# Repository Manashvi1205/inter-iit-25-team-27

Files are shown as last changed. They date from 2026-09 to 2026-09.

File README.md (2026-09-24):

# Autonomous Rover for Warehouse Rack Inventory

Warehouse records drift. Items get picked, put back on the wrong shelf, or never scanned, and the database stops matching the rack. This rover closes that gap on the floor. It drives the aisle, stops in front of a bay, runs a camera up the rack face, reads the label at each level, and writes the result to a live inventory view.

The machine is a full mobile robot, not a camera on a stick. A ~25 kg differential-drive base carries compute, LiDAR, batteries, and motor drivers. A belt-driven mast lifts the camera from the floor to about 1.8 m. Three Arduino Megas and an ESP32 handle motors, encoders, the IMU, and the pan-tilt, while a Jetson Orin Nano runs ROS 2 navigation and the scan.

The design targets are concrete: align with a rack to better than ±10 cm horizontally and ±2 cm vertically, scan a 1.8 m rack segment in under 3 minutes at 1920×1080, decode 5 cm labels with better than 90% success, and stop in under 500 ms on an emergency press.

<p align="center">
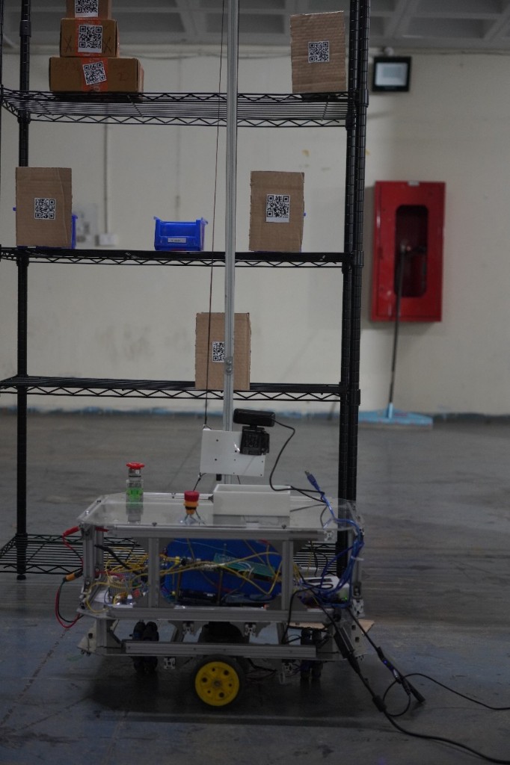
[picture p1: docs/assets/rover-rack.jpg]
Rover stopped at a rack with the camera carriage on the mast
  
</p>

The rover in front of a rack. The camera carriage sits on the mast; the clear deck holds the battery, controllers, and emergency stop.

---

## How a run works

1. The operator gives a goal in the mapped warehouse. Nav2 plans a path on the occupancy grid and the base drives to the bay.
2. The base settles in front of the rack. Wheel encoders, the BNO055, and the RPLiDAR keep the pose stable enough for the camera to face the shelf.
3. The IG45 lift motor runs the timing belt until the carriage is at the next shelf height. Encoder ticks are mapped at 163 ticks per centimetre of travel.
4. If a label sits at the edge of the frame, two SC15 servos pan and tilt the camera. The IMX258 then captures the shelf.
5. The vision node detects the code, projects it onto the rack plane, and logs rack, shelf, item id, and pose. Duplicates from the same stop are dropped.
6. The Flask dashboard reads that table and shows which slots are filled, which are empty, and what the rover just did.

Two streams run at once. Motion data (`/scan`, `/imu`, `/odom`) stays on the Jetson and never waits for the website. Scan results are written beside that pipeline and served to the operator over HTTP, so a slow browser refresh cannot stall navigation.

---

## Base

The footprint stays inside 600 mm × 450 mm so the robot can turn inside an aisle. The centre of rotation sits near the geometric centre: two driven wheels on the sides, one caster at the front and one at the rear. All four share the load, and the corners stay inside the clearance next to the racks.

The load-bearing plate is 3 mm aluminium. The other decks are 3 mm acrylic, held in 2020 aluminium extrusion with M5 fasteners (M4 and M3 on mounts and hubs). Mild-steel shafts carry the rotating parts. Edges are chamfered and covered by the extrusion so there are no sharp corners at shin height.

<p align="center">
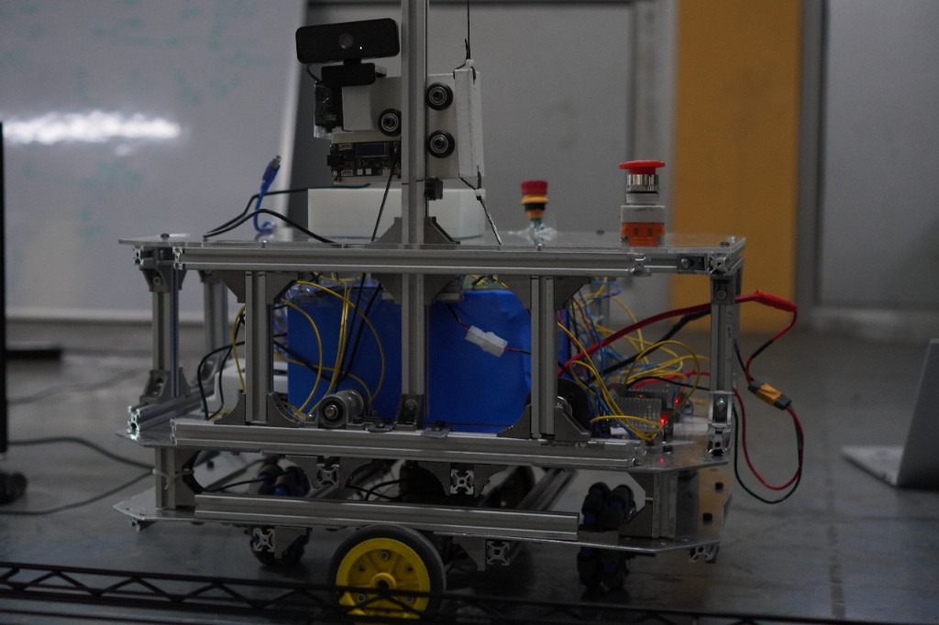
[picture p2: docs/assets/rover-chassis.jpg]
Side view of the aluminium chassis, batteries, wiring, and emergency stop
  
</p>

Drive is two IG42 planetary gearmotors with built-in encoders, through one Cytron MDD10A. The Mega closes the speed loop from the encoder counts and publishes wheel odometry to the Jetson over serial. HD rubber wheels are sized for smooth warehouse floors: enough grip to start and stop a 25 kg robot without the slip that would wreck the odometry.

The second MDD10A drives the mast motor on the same style of PWM and direction interface, so base and lift look the same to the controller. The Jetson sends velocity and a Z target; the Mega turns those into PWM.

---

## Mast

Vertical travel is a continuous timing belt on a rigid extrusion column. The belt stays in one plane over the motor pulley, a top idler, and an in-line idler, so the carriage is pulled both up and down instead of relying on friction. A long bolt acts as a passive tensioner. Guided rollers keep the carriage from twisting when the camera and servo board are on it.

Clockwise rotation of the IG45 lowers the carriage; counter-clockwise raises it. Because the column is stiff, the lift does not run a second position loop on the Jetson. A constant PWM runs until the encoder count matches the shelf height. Limit switches at the top and bottom are wired normally closed and cut the motor if the carriage travels past the stroke.

On the carriage, two SC15 bus servos add pan and tilt. A Waveshare ESP32 board on the carriage drives them and reports angle, so the vision node knows where the camera was pointing when the frame was taken. At the end of a session the camera is sent back to a recorded home pose.

<p align="center">
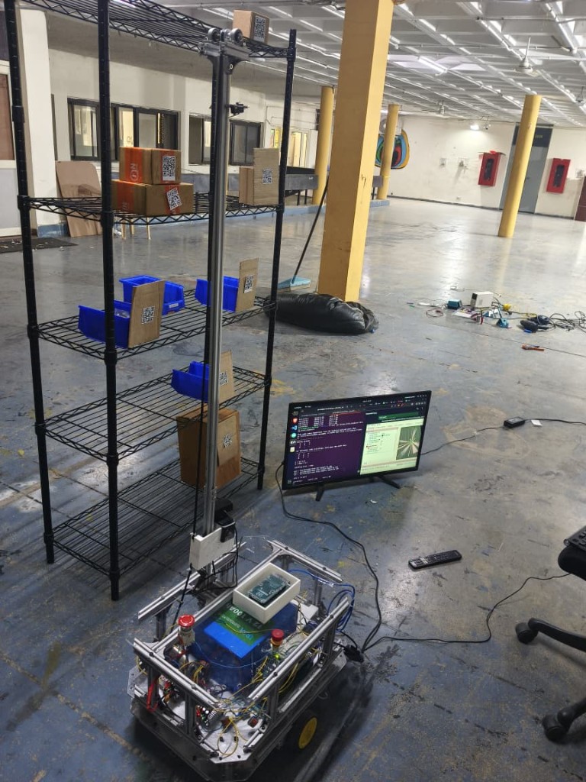
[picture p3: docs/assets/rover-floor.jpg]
Full rover on the warehouse floor, mast raised beside a rack, LiDAR view on a monitor
  
</p>

---

## Navigation

Localisation is three measurements fused on purpose.

- Wheel encoders give short-term motion, including the lift height.
- The BNO055, on its own Mega over I2C, publishes fused orientation. The chip does the sensor fusion onboard and outputs a quaternion, so the robot does not run a separate attitude filter.
- The RPLiDAR S2E sweeps 360° out to 30 m at over 10 kHz. It talks to the Jetson over Ethernet, not USB, for bandwidth and noise. The laser is eye-safe for people working next to the aisle.

An EKF (`robot_localization`) fuses encoders and IMU into `/odom` and the `odom` → `base_link` transform. SLAM Toolbox consumes `/scan` plus that pose, builds a 2D occupancy grid, and publishes `map` → `odom`, which is what removes long-term drift. The static `base_link` → `laser` transform is the LiDAR mount.

Nav2 plans on that map. The global planner is NavFn with A*. The local controller is DWB: it samples twists around the nominal command and scores them against the costmaps, which matters because the two drive motors are not perfectly matched and the base would otherwise walk off the path. Costmaps are layered — static map, live obstacle inserts from the LiDAR, and an inflation layer around the footprint. If the local planner cannot find a safe command, the behaviour tree clears the costmap, spins, or replans.

<p align="center">
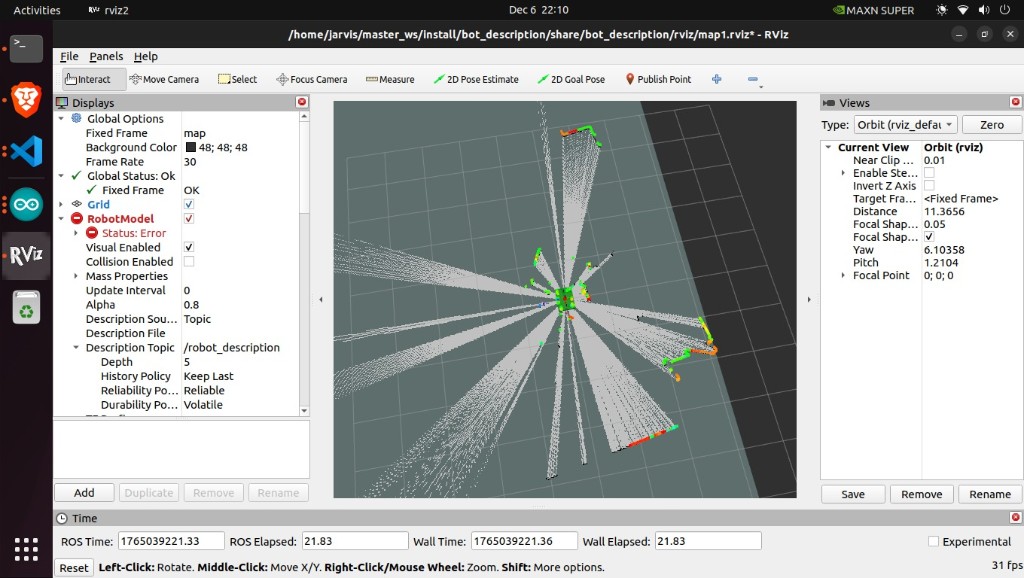
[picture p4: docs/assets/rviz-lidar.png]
RViz showing a live RPLiDAR scan while the rover is mapping
  
</p>

---

## Scanning

The camera is a Waveshare IMX258, 13 MP, with optical image stabilisation, on USB so the cable run up the mast stays simple. Capture waits until the lift and the servos have settled, then grabs a frame.

Detection is a two-stage read. A detector proposes QR regions. Those regions are warped onto the rack plane with a homography, cleaned up for indoor lighting, and decoded. Each hit is stored with rack id, shelf, payload, confidence, and the robot pose at that moment. The same code seen twice in one stop is not logged twice. Annotated frames can be saved when a threshold needs tuning.

Results land in `inventory.csv`. The dashboard does not talk to ROS directly. A Flask app reads the CSVs (`rover_data.csv` for telemetry, `racks.csv` for the layout, `inventory.csv` for scans) and the page polls JSON. Operators get rack cards, an event log with timestamps, and buttons for a normal capture, a top or bottom look, or a full sweep, plus LED and servo controls. Login is session-based; the demo password in the HMI README should be changed before the page is reachable off the robot.

---

## Power and safety

A 12.8 V LiFePO4 pack feeds a small distribution board. Wiring on the battery input is rated to 50 A for acceleration and lift peaks.

| Rail | What it feeds |
|---|---|
| Battery bus, 12.8 V | Both Cytron MDD10A drivers, through a fuse: IG42 base motors and the IG45 lift |
| 7 V buck, 12 A | Three Arduino Megas, the ESP32 servo board, IMU, status LEDs, buzzer |
| 12 V buck, 12 A | Jetson Orin Nano and the LiDAR, on a fused branch that normally stays under 2 A |

Logic ground and power ground meet at one point on the board so encoder and serial lines stay quiet.

<p align="center">
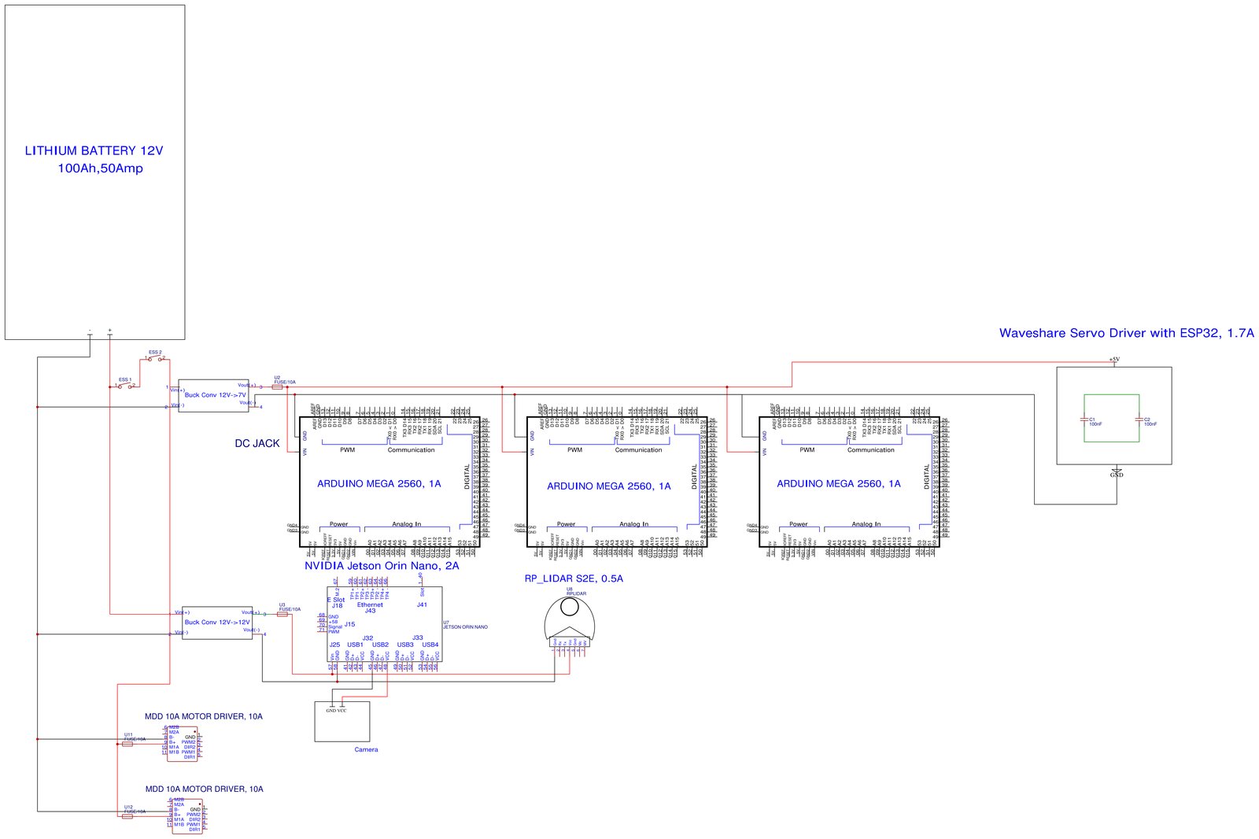
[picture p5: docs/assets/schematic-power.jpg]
Power schematic from the battery to the Megas, Jetson, LiDAR, and motor drivers
  
</p>

Emergency-stop buttons sit on both sides and open the drive. Status LEDs and a buzzer report state without requiring the dashboard. Speed and acceleration are capped in software. Encoder feedback flags a stalled wheel. The Jetson can also command an immediate stop from the obstacle layer; the Mega applies it through the drivers.

---

## Mechanical drawings

Assembly of the full machine. The long member on the right of the side view is the mast. Overall length on the drawing is about 1.62 m with the mast laid in the view; the base itself is the compact chassis described above.

<p align="center">
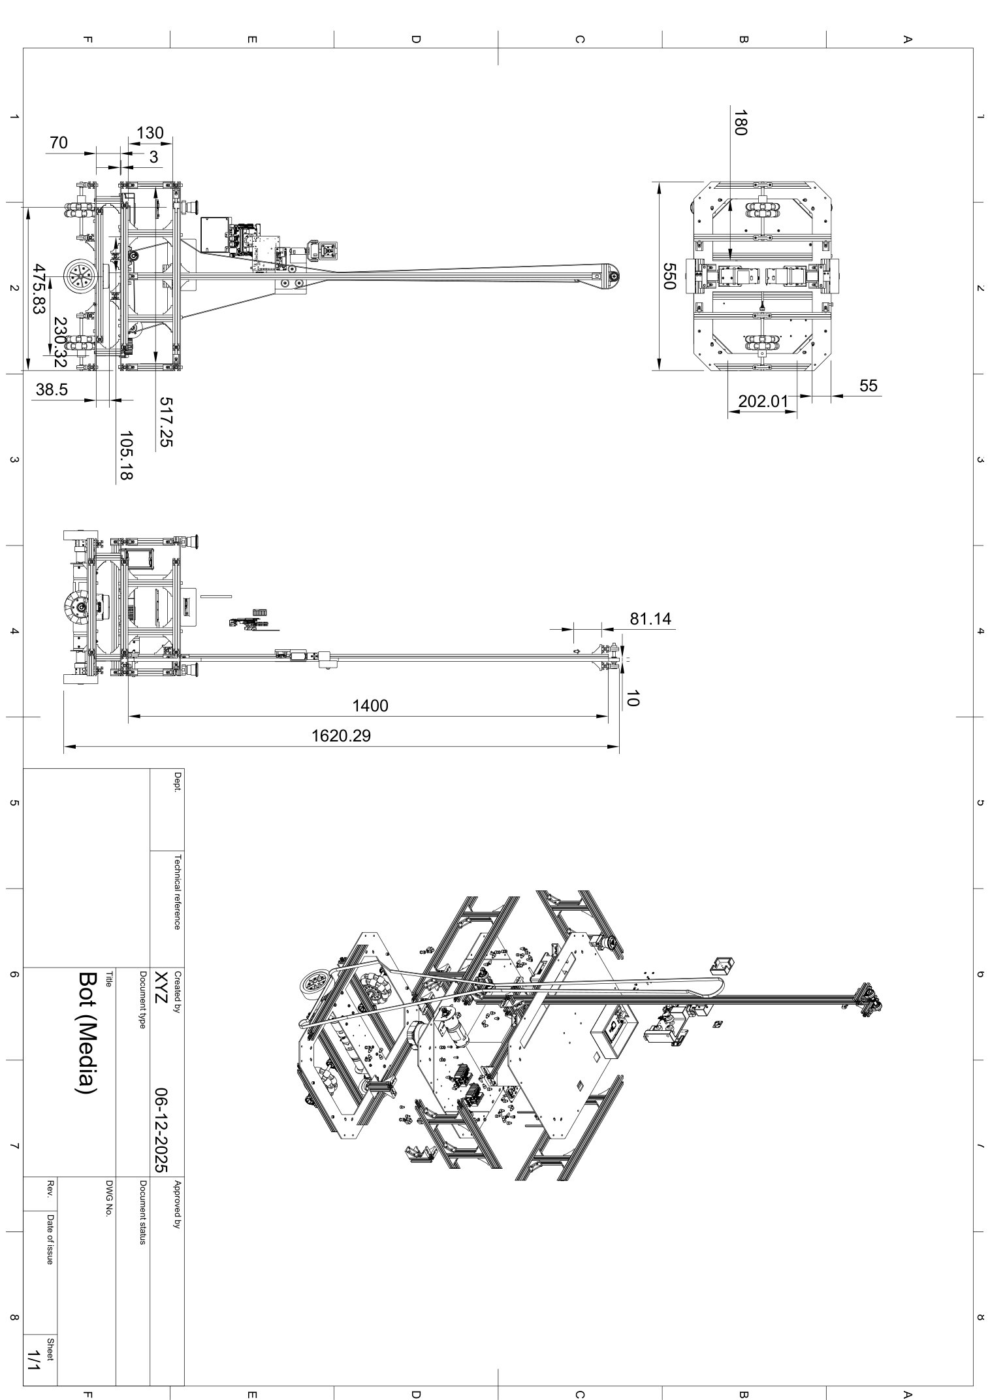
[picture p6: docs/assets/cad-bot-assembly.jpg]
Assembly drawing of the rover and mast
  
</p>

Drive side: wheel spacing, motor mounts, and the caster line that puts the spin centre near the middle of the base.

<p align="center">
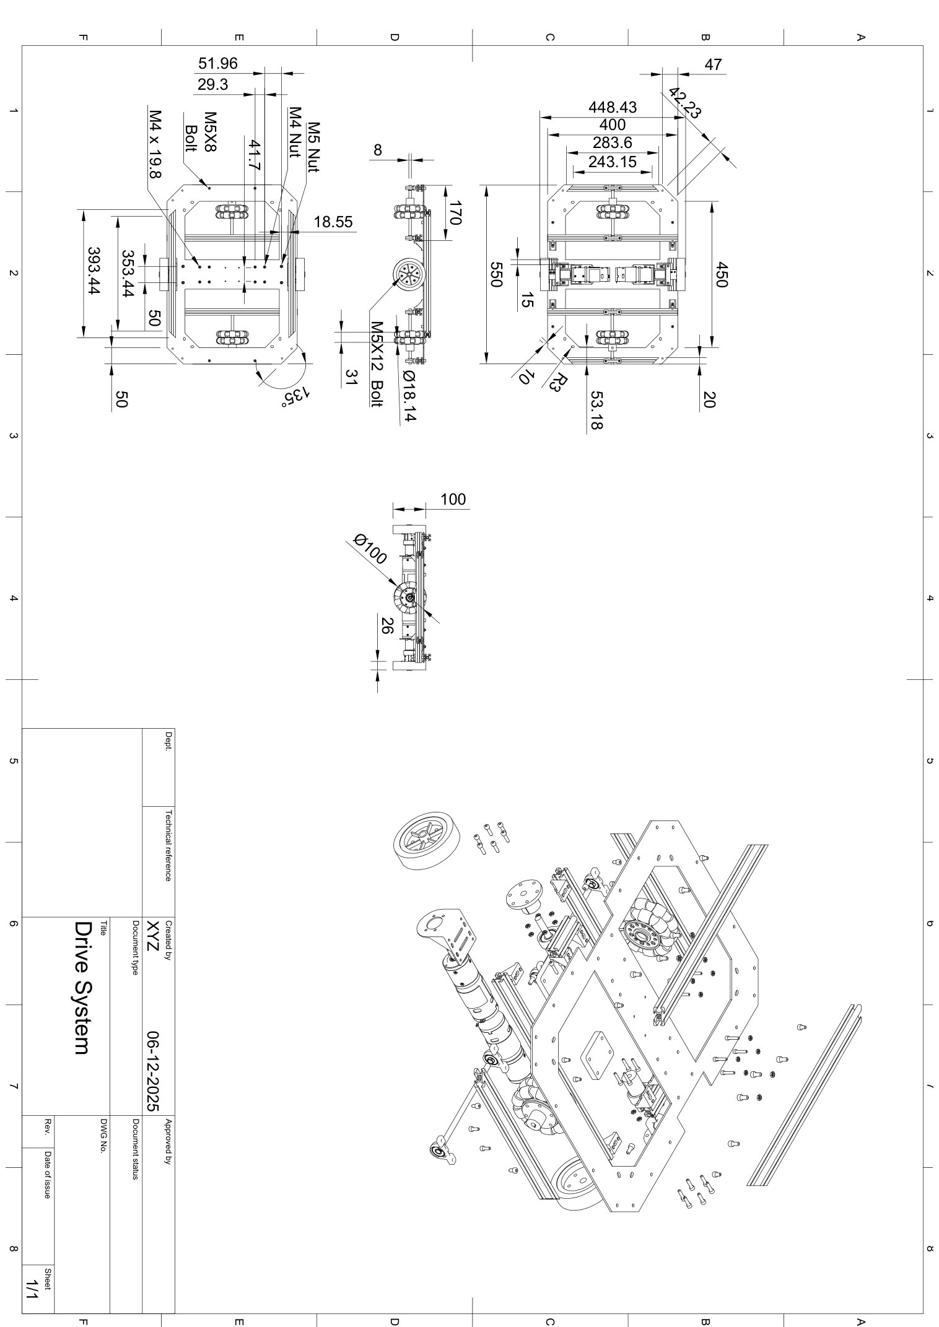
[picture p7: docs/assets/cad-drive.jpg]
Drive system drawing
  
</p>

Camera carriage: the head that rides the belt, with the pan-tilt in front of the shelf.

<p align="center">
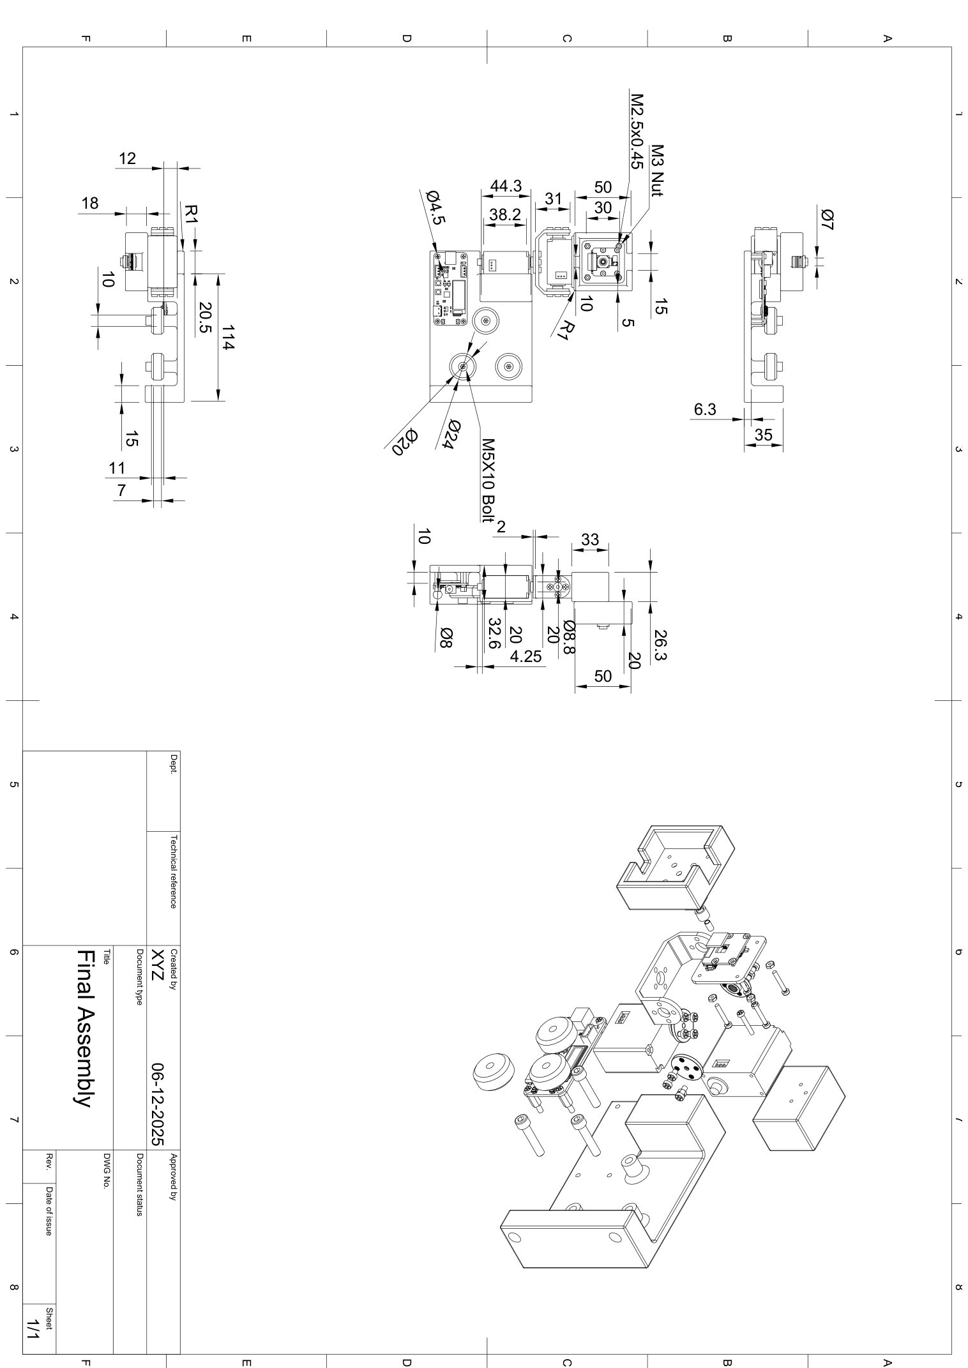
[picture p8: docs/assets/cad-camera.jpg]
Camera carriage drawing
  
</p>

STEP model and the source PDFs: [`hardware/CAD_Models/CAD and Drawings/`](hardware/CAD_Models/CAD%20and%20Drawings). Bill of materials: [`hardware/BOM.csv`](hardware/BOM.csv). Schematics: [`hardware/Electrical_Schematics/`](hardware/Electrical_Schematics). Full write-up: [`docs/technical-documentation.pdf`](docs/technical-documentation.pdf).

---

## Software in the repo

```
code/
  src/src/
    bot_description    URDF, Gazebo worlds, RViz configs
    bot_bringup        Nav2 params, EKF, bringup launch, commander
    bot_broadcaster    odometry, IMU, joint states, cmd_vel to the Mega
    bot_scanning       lift, servos, capture, QR pipeline
    rplidar_ros        Slamtec driver
  Utils/               Arduino sketches: drive, odometry, IMU, servos, LEDs, buzzer
  hmi/                 Flask dashboard
hardware/              CAD, BOM, schematics, demo videos
vision/                earlier scanner experiments and notes
```

`code/` is the robot. `vision/` is lab history.

On the Jetson, after a colcon build and `source install/setup.bash`:

```bash
ros2 launch bot_bringup my_bot.launch.py
```

Dashboard, from `code/hmi`:

```pwsh
python -m venv .venv
.\.venv\Scripts\Activate.ps1
pip install -r requirements.txt
python app.py
```

Open `http://localhost:5000`. The robot posts telemetry and shelf updates to `POST /api/update`.

Demo clips, stored with Git LFS: [driving and obstacle avoidance](hardware/Videos/obstacle_avoidance.mov), [mast scan](hardware/Videos/Vertical_scanning.mov), [SLAM](hardware/Videos/Slam.mov), [dashboard](hardware/Videos/HMI.mov).

```bash
git lfs install
git clone https://github.com/Manashvi1205/warehouse-rover.git
```

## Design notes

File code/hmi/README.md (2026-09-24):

# Eternal Rover Mission Control — Inter IIT Tech Meet 14.0

A compact mission-control dashboard for the Autonomous Rover. Visualizes real-time telemetry, manages mission rounds, and maps warehouse inventory (Racks A–F) from Jetson Nano POSTs.

---

## Table of Contents
- [Quick Start](#quick-start)
- [Project Structure](#project-structure)
- [Accessing the Dashboard](#accessing-the-dashboard)
- [API / Jetson Nano Integration](#api--jetson-nano-integration)
- [Payload Fields](#payload-fields)
- [Examples](#examples)
- [Warehouse Configuration](#warehouse-configuration)

---

## Quick Start

Recommended: create and activate a virtual environment, then install dependencies.

```pwsh
python -m venv .venv
.\.venv\Scripts\Activate.ps1
pip install -r requirements.txt
```

Two ways to run:

- Fresh start (clears old CSVs and restarts):

```pwsh
python restart_run.py
```

- Resume mission (keep existing data):

```pwsh
python app.py
```

---

## Project Structure

- `app.py` — Main Flask server and API handlers.
- `restart_run.py` — Utility to clear data and restart a fresh session.
- `test.py` — Simulator to exercise the dashboard without hardware.
- `templates/` — HTML templates (e.g., `dashboard.html`, `dashboard_login.html`).
- `*.csv` — Generated data files (e.g., `rover_data.csv`, `inventory.csv`).

---

## Accessing the Dashboard

Open a browser to:

```
http://localhost:5000
```

Default login

```
Username: admin
Password: password
```

---

## API / Jetson Nano Integration

Endpoint: `POST /api/update`

Content-Type: `application/json`

This endpoint accepts telemetry and inventory scan updates. All fields are optional; include the fields you have available.

### Payload Fields

| Field | Type | Description | Example |
|---|---:|---|---|
| `battery_level` | number | Battery percentage (0–100) | `88.5` |
| `cpu_temp` | number | CPU temperature in °C | `45.2` |
| `status` | string | Short status message | `"Scanning"` |
| `current_task` | string | Current task description | `"Moving to Rack B"` |
| `coordinates` | string | Position as `x, y` | `"12.5, 4.0"` |
| `shelf_id` | string | Inventory slot identifier (Rack-Level) — e.g. `A-05` | `"A-05"` |
| `shelf_status` | string | Shelf state: `Empty` or `Full` | `"Empty"` |
| `new_round` | boolean | If `true`, forces a new mission round | `true` |

---

## Examples

1) Telemetry-only update (Python requests):

```python
import requests

SERVER_URL = "http://<DASHBOARD_IP>:5000/api/update"

payload = {
    "battery_level": 75.0,
    "cpu_temp": 55.0,
    "status": "Navigating",
    "coordinates": "1.2, 3.4"
}

requests.post(SERVER_URL, json=payload)
```

2) Shelf scan update (updates visual grid):

```python
scan_payload = {
    "status": "Scanning",
    "shelf_id": "C-03",      # Valid: A-01 to F-05
    "shelf_status": "Empty"  # Will mark the box as empty on the dashboard
}
requests.post(SERVER_URL, json=scan_payload)
```

3) Start a new round (reset map):

```python
requests.post(SERVER_URL, json={"new_round": True})
```

---

## Warehouse Configuration

Default layout (blueprint):

- Racks: `A`, `B`, `C`, `D`, `E`, `F` (6 racks)
- Levels per rack: `01` to `05` (5 levels)
- Total slots: 30

To change these values, edit the `WAREHOUSE_MAPPING` (or relevant constants) in `app.py`.

---

If you want, I can:
- Add a short curl example for testing the API from a terminal.
- Add a Dockerfile to containerize the dashboard.
- Convert this README into a more detailed developer guide.

Generated and formatted for readability.

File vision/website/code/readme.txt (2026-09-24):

->>>> @jarvis-desktop:~/Inter_IIT$ source ultron/bin/activate

Wechat require opencv contribution 
model requires file in the same parent directory
run in virutal env
debug contains a josn for output data forn  each level

SERVO
pyserial required               
-> find usb port using  '  ls /dev/ttyUSB*  '
maybe:  /dev/ttyUSB0 
-> port permission is rquired to access the port
give perm and reboot: sudo usermod -aG dialout $USER
                next: sudo reboot

->AUTOFOCUS : 0 -OFF,1-ON'v4l2-ctl -d /dev/video0 --set-ctrl=focus_automatic_continuous=1'
MANUAL  FOCUS: ' v4l2-ctl -d /dev/video0 --set-ctrl=focus_absolute=200'

servo_move_to_delay  can be reduced!!!!!
write this function: 'remove_duplicates_across_poses' ,

ISSUES:
MULTIPLE IMAGES CASUING ISSUUES -> DIFFERENT SCAN STILL SAME QR DATA, STILL STORED... NEEDS FIX

ALSO NO BOUNDING BOX!!? WHY??
CREATE BOUNDING BOX..(RESOLVED)
ALSO THE DEBUG IS FALSE BY DEFAULT CAUSING ISSUES!!(STILL NEEDS FIXES)
=> entire code for debug output needs to be fixecds!!
 => hommography incorporate karna hai!!
=> also once the scanning finish it should go back to Home that is (1,1) position
=> also if the output path/directory is  not present then create one and use.. do not throw such errors... print in logs/consol as required!

NEXT(2/DEC)

 => hommography incorporate karna hai!!
 => return HOME SEQUENCE 
 => CLIBRATE SERVOS (done)
 => RGB (done)

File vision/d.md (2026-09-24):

# Warehouse QR Scanning System - Complete Technical Overview

## System Architecture Overview

This is a **real-time warehouse inventory management system** that uses computer vision to detect and process 
QR codes on shelves, mapping them to global coordinates via SLAM integration.

---

## 1. High-Level System Architecture

```
┌─────────────────────────────────────────────────────────────────┐
│                        WAREHOUSE ENVIRONMENT                     │
│  ┌──────────┐  ┌──────────┐  ┌──────────┐  ┌──────────┐       │
│  │ Rack R01 │  │ Rack R02 │  │ Rack R03 │  │ Rack R04 │       │
│  │ ┌──────┐ │  │ ┌──────┐ │  │ ┌──────┐ │  │ ┌──────┐ │       │
│  │ │ QR   │ │  │ │ QR   │ │  │ │ QR   │ │  │ │ QR   │ │       │
│  │ └──────┘ │  │ └──────┘ │  │ └──────┘ │  │ └──────┘ │       │
│  └──────────┘  └──────────┘  └──────────┘  └──────────┘       │
└─────────────────────────────────────────────────────────────────┘
                              │
                              ▼
┌─────────────────────────────────────────────────────────────────┐
│                     HARDWARE LAYER                               │
│  ┌────────────────┐  ┌────────────────┐  ┌──────────────────┐  │
│  │  USB Camera    │  │  Servo Motors  │  │  LED Controller  │  │
│  │  (640x480)     │  │  (Pan/Tilt)    │  │  (Status LEDs)   │  │
│  └────────┬───────┘  └────────┬───────┘  └────────┬─────────┘  │
└───────────┼──────────────────┼───────────────────┼─────────────┘
            │                  │                   │
            ▼                  ▼                   ▼
┌─────────────────────────────────────────────────────────────────┐
│                   SOFTWARE LAYER (Python)                        │
│  ┌────────────────────────────────────────────────────────────┐ │
│  │              visionNode (Orchestrator)                      │ │
│  │  • Singleton coordinator                                   │ │
│  │  • LED status control                                      │ │
│  │  • Multi-angle scanning logic                              │ │
│  └────────────────┬───────────────────────────────────────────┘ │
│                   │                                              │
│       ┌───────────┴───────────┐                                 │
│       ▼                       ▼                                 │
│  ┌─────────┐           ┌───────────┐                           │
│  │ Scanner │           │ Processor │                            │
│  │ Module  │           │  Worker   │                            │
│  └─────────┘           └───────────┘                            │
└─────────────────────────────────────────────────────────────────┘
            │                       │
            ▼                       ▼
┌─────────────────────────────────────────────────────────────────┐
│                     DATA LAYER                                   │
│  ┌──────────────┐  ┌──────────────┐  ┌──────────────────────┐  │
│  │ Raw Images   │  │ Inventory DB │  │  Remote API Server   │  │
│  │  (PNG)       │  │  (CSV)       │  │  (HTTP POST)         │  │
│  └──────────────┘  └──────────────┘  └──────────────────────┘  │
└─────────────────────────────────────────────────────────────────┘
```

---

## 2. Hardware Subsystems

### 2.1 Camera System
```
┌────────────────────────────────────────┐
│         USB Camera (V4L2)              │
│  • Resolution: 640x480 pixels          │
│  • Codec: MJPEG                        │
│  • FPS: 30                             │
│  • Backend: CAP_V4L2 (Linux)          │
└────────────────────────────────────────┘
```

### 2.2 Servo System
```
┌────────────────────────────────────────┐
│      2-Axis Servo Pan/Tilt Mount      │
│                                        │
│  Servo 0 (Horizontal):                │
│  • Range: 0-180°                      │
│  • Positions: Left(0), Center(1), Right(2) │
│                                        │
│  Servo 1 (Vertical):                  │
│  • Range: 0-180°                      │
│  • Positions: Down(0), Front(1), Up(2) │
│                                        │
│  Control: Serial @ 115200 baud        │
└────────────────────────────────────────┘
```

### 2.3 LED System
```
┌────────────────────────────────────────┐
│       RGB LED Status Indicators        │
│  • Signal Yellow: Warning              │
│  • Signal Red: Danger                  │
│  • Signal Green: Safe/Complete         │
│  • Signal Blue: Mandatory              │
│  • White: Flashlight mode              │
└────────────────────────────────────────┘
```

---

## 3. Complete Control Flow

### 3.1 System Initialization Sequence

```
START
  │
  ├─► [1] Load YAML Configuration
  │     │
  │     ├── camera_cfg (resolution, FPS, codec)
  │     ├── processor_cfg (thresholds, paths)
  │     ├── scanner_cfg (servo ports, LED settings)
  │     └── session_cfg (session_id, API URL)
  │
  ├─► [2] Initialize visionNode Singleton
  │     │
  │     ├── Create log directories
  │     ├── Initialize Scanner subsystem
  │     │     ├── Try cameras [0, 1, 2] in sequence
  │     │     ├── Set camera properties (width, height, FPS)
  │     │     ├── Warmup period (150ms)
  │     │     └── Initialize servo board (optional)
  │     │
  │     └── Launch Processor Worker (multiprocessing)
  │           ├── Create Queue (maxsize=20)
  │           ├── Create Stop Event
  │           └── Spawn background process
  │
  └─► [3] System Ready
        • Scanner: Active on camera device
        • Processor: Waiting for jobs
        • Servos: At neutral position (H=1, V=1)
```

---

### 3.2 Main Scanning Pipeline

```
┌─────────────────────────────────────────────────────────────────┐
│                    CAPTURE REQUEST                               │
│  visionNode.capture(x, y, isTop, isBottom)                      │
└──────────────────────┬──────────────────────────────────────────┘
                       │
                       ▼
        ┌──────────────────────────────┐
        │  Determine Scan Strategy     │
        │  • Normal: 1 angle           │
        │  • Top: 2 angles (1→2)       │
        │  • Bottom: 2 angles (1→0)    │
        │  • Full: 3 angles (0→1→2)    │
        └──────────┬───────────────────┘
                   │
                   ▼
        ┌──────────────────────────────┐
        │   FOR EACH ANGLE:            │
        │   1. Move Servo              │
        │   2. Wait 250ms              │
        │   3. Capture Frame           │
        └──────────┬───────────────────┘
                   │
                   ▼
┌─────────────────────────────────────────────────────────────────┐
│                  FRAME CAPTURE (Scanner)                         │
│                                                                  │
│  [1] Burst Capture (10 frames)                                  │
│      ├── Flush camera buffer (3 frames)                         │
│      ├── Use grab() for fast acquisition                        │
│      └── Use retrieve() to decode frames                        │
│                                                                  │
│  [2] Sharpness Analysis                                         │
│      ├── Convert to grayscale                                   │
│      ├── Apply Laplacian operator                               │
│      ├── Compute variance                                       │
│      └── Select frame with highest score                        │
│                                                                  │
│  [3] Save Best Frame                                            │
│      ├── Filename: capture_YYYY-MM-DD_HH-MM-SS.png             │
│      ├── Save to: /data/raw_captures/                          │
│      └── Log metadata to CSV                                    │
└──────────────────────┬──────────────────────────────────────────┘
                       │
                       ▼
        ┌──────────────────────────────┐
        │   Queue for Processing       │
        │   • path: image filepath     │
        │   • x0: SLAM x coordinate    │
        │   • y0: SLAM y coordinate    │
        │   • orientation: 0/1/2       │
        └──────────┬───────────────────┘
                   │
                   ▼
┌─────────────────────────────────────────────────────────────────┐
│            PROCESSOR WORKER (Background Process)                 │
│                                                                  │
│  [1] Load Image                                                 │
│      └── cv2.imread(path)                                       │
│                                                                  │
│  [2] Geometric Rectification                                    │
│      ├── Map orientation → (theta, phi)                         │
│      │   • 0 (down):  theta=180°, phi=90°                      │
│      │   • 1 (front): theta=90°,  phi=90°                      │
│      │   • 2 (up):    theta=0°,   phi=90°                      │
│      │                                                          │
│      ├── Build rotation matrix R                                │
│      ├── Project each pixel onto wall plane                     │
│      └── Create rectified image                                 │
│                                                                  │
│  [3] QR Detection                                               │
│      ├── Run YOLO-based QRDetector                             │
│      ├── Extract bounding boxes [x1,y1,x2,y2]                  │
│      ├── Calculate centroids (u_center, v_center)              │
│      └── Crop with padding                                      │
│                                                                  │
│  [4] QR Enhancement & Decoding                                  │
│      ├── Resize to 400x400                                      │
│      ├── Apply CLAHE contrast enhancement                       │
│      ├── Apply Unsharp Mask                                     │
│      ├── Binary threshold                                       │
│      └── WeChat QR decoder                                      │
│                                                                  │
│  [5] Coordinate Transformation                                  │
│      ├── UV (pixels) → Camera Frame (meters)                   │
│      │   x_cam = (u/ppm) + x_cam_origin                        │
│      │   y_cam = y_cam_origin - (v/ppm)                        │
│      │                                                          │
│      └── Camera Frame → Global Frame                            │
│          global_x = x_cam + x_offset (SLAM)                    │
│          global_y = y_cam + y_offset (SLAM)                    │
│                                                                  │
│  [6] Inventory Management                                       │
│      ├── Parse payload: "R03_S4_ITM240"                        │
│      │   → rack="R03", shelf="S4", item="ITM240"              │
│      │                                                          │
│      ├── Read existing inventory CSV                            │
│      │                                                          │
│      ├── Duplicate Detection                                    │
│      │   • Same item + Same location → IGNORE                  │
│      │   • Same item + New location → NEW ENTRY                │
│      │   • New item → NEW ENTRY                                │
│      │                                                          │
│      ├── Save to inventory.csv                                  │
│      └── POST to remote API                                     │
└─────────────────────────────────────────────────────────────────┘
```

---

## 4. Coordinate System Transformations

### 4.1 Three Coordinate Frames

```
┌────────────────────────────────────────────────────────────────┐
│  [1] UV FRAME (Image Pixels)                                   │
│                                                                 │
│      (0,0) ────────► u                                         │
│        │                                                        │
│        │   ┌───────────────┐                                   │
│        │   │               │                                   │
│        ▼   │    QR Code    │                                   │
│        v   │   @ (u,v)     │                                   │
│            │               │                                   │
│            └───────────────┘                                   │
│                                                                 │
│  Origin: Top-left corner                                       │
│  Units: Pixels                                                 │
└────────────────────────────────────────────────────────────────┘

┌────────────────────────────────────────────────────────────────┐
│  [2] CAMERA FRAME (3D Space)                                   │
│                                                                 │
│                     y_cam (up)                                 │
│                       ▲                                         │
│                       │                                         │
│            ┌──────────┼──────────┐                            │
│            │          │          │                             │
│            │     Wall Plane      │                             │
│            │     (d = 0.2m)      │                             │
│            │          │          │                             │
│  ◄─────────┼──────────●──────────┼──────► x_cam (right)      │
│            │     Camera Optical  │                             │
│            │       Center        │                             │
│            └─────────────────────┘                             │
│                                                                 │
│  Origin: Camera optical center projected onto wall             │
│  Units: Meters                                                 │
│  Distance to wall: d = 0.20m                                   │
└────────────────────────────────────────────────────────────────┘

┌────────────────────────────────────────────────────────────────┐
│  [3] GLOBAL FRAME (SLAM Coordinates)                           │
│                                                                 │
│                                                                 │
│         Warehouse Floor Plan                                   │
│                                                                 │
│    (x_offset, y_offset) ───► Global Origin                    │
│           │                                                     │
│           ▼                                                     │
│    ┌──────────┐  ┌──────────┐  ┌──────────┐                  │
│    │ Rack 01  │  │ Rack 02  │  │ Rack 03  │                  │
│    │          │  │          │  │          │                  │
│    │  QR @    │  │          │  │          │                  │
│    │ (gx, gy) │  │          │  │          │                  │
│    └──────────┘  └──────────┘  └──────────┘                  │
│                                                                 │
│  Origin: SLAM/Odometry world origin                            │
│  Units: Meters                                                 │
│  Transformation: (global_x, global_y) = (x_cam, y_cam) +       │
│                  (x_offset, y_offset)                          │
└────────────────────────────────────────────────────────────────┘
```

### 4.2 Transformation Pipeline

```python
# STEP 1: UV → Camera Frame
# ─────────────────────────────────────
# 1. Get camera ray direction
ray_cam = [(u - c_x)/f_x, (v - c_y)/f_y, 1.0]

# 2. Apply rotation matrix (camera orientation)
R = rotation_matrix(theta, phi)
ray_world = R @ ray_cam

# 3. Intersect ray with wall plane at distance d
t = d / ray_world[1]  # y-component
x_cam = t * ray_world[0]
y_cam = t * ray_world[2]

# STEP 2: Camera Frame → Global Frame
# ─────────────────────────────────────
global_x = x_cam + x_offset  # SLAM X offset
global_y = y_cam + y_offset  # SLAM Y offset
```

---

## 5. Data Flow Diagram

```
┌─────────────────────────────────────────────────────────────────┐
│                    INPUT LAYER                                   │
│                                                                  │
│  ┌──────────────┐  ┌──────────────┐  ┌──────────────────────┐  │
│  │ SLAM System  │  │  Scan Cmd    │  │   Camera Hardware    │  │
│  │ (x, y, θ)    │  │ (isTop/Bot)  │  │   (Raw Frames)       │  │
│  └──────┬───────┘  └──────┬───────┘  └──────┬───────────────┘  │
└─────────┼──────────────────┼──────────────────┼──────────────────┘
          │                  │                  │
          ▼                  ▼                  ▼
┌─────────────────────────────────────────────────────────────────┐
│                 PROCESSING LAYER                                 │
│                                                                  │
│  ┌────────────────────────────────────────────────────────────┐ │
│  │                   visionNode                                │ │
│  │  • Coordinate visionNode.capture()                         │ │
│  │  • LED status control                                       │ │
│  │  • Multi-angle logic                                        │ │
│  └──────┬─────────────────────────────────────────────────────┘ │
│         │                                                        │
│         ├──► Scanner.capture_best_frame()                       │
│         │      ├── Burst capture (10 frames)                    │
│         │      ├── Sharpness selection                          │
│         │      └── Save to disk                                 │
│         │                                                        │
│         └──► Processor Worker (background)                      │
│                ├── Load image                                   │
│                ├── Geometric rectification                      │
│                ├── QR detection (YOLO)                          │
│                ├── QR decoding (WeChat)                         │
│                ├── Coordinate transform                         │
│                └── Inventory update                             │
│                                                                  │
└─────────┬───────────────────────────────────────────────────────┘
          │
          ▼
┌─────────────────────────────────────────────────────────────────┐
│                   OUTPUT LAYER                                   │
│                                                                  │
│  ┌──────────────────┐  ┌──────────────────┐  ┌───────────────┐ │
│  │  inventory.csv   │  │  Remote API      │  │  Log Files    │ │
│  │                  │  │  POST /session   │  │  (Debug)      │ │
│  │  session_id      │  │                  │  │               │ │
│  │  timestamp       │  │  {               │  │               │ │
│  │  payload         │  │    round_id,     │  │               │ │
│  │  rack            │  │    timestamp,    │  │               │ │
│  │  shelf           │  │    payload,      │  │               │ │
│  │  item            │  │    shelf_status  │  │               │ │
│  │  global_x        │  │  }               │  │               │ │
│  │  global_y        │  │                  │  │               │ │
│  └──────────────────┘  └──────────────────┘  └───────────────┘ │
└─────────────────────────────────────────────────────────────────┘
```

---

## 6. Detailed Module Breakdown

### 6.1 visionNode.py (Orchestrator)

**Purpose**: High-level coordinator that manages the entire scanning workflow

**Key Responsibilities**:
```
├── System Initialization
│   ├── Load configuration
│   ├── Initialize Scanner hardware
│   └── Launch Processor worker
│
├── Scan Strategy Execution
│   ├── Single-angle capture
│   ├── Top-sweep (normal → up)
│   ├── Bottom-sweep (normal → down)
│   └── Full-sweep (down → normal → up)
│
├── LED Status Control
│   ├── Warning (yellow)
│   ├── Danger (red)
│   ├── Safe (green)
│   └── Flashlight (white)
│
└── Worker Management
    ├── Queue management
    ├── Job distribution
    └── Graceful shutdown
```

**Key Methods**:
- `capture(x, y, isTop, isBottom)` - Main scanning API
- `capture_once(x, y, orientation)` - Single frame capture
- `led(color, level, index)` - LED control
- `shutdown()` - Clean resource cleanup

---

### 6.2 Scanner.py (Hardware Interface)

**Purpose**: Direct hardware control for camera and servos

**Key Responsibilities**:
```
├── Camera Management
│   ├── Device selection (tries [0,1,2])
│   ├── Property configuration
│   ├── Burst capture
│   └── Sharpness analysis (Laplacian variance)
│
├── Servo Control
│   ├── Position commands
│   ├── Calibration
│   └── Status queries
│
└── File Management
    ├── Image saving
    ├── Metadata logging (CSV)
    └── Error logging
```

**Burst Capture Algorithm**:
```python
1. Flush buffer (3 frames)
2. FOR i in range(10):
     - grab() frame (fast)
     - retrieve() frame (decode)
     - compute sharpness
     - if sharpness > best:
         save as best_frame
3. Save best_frame to disk
4. Log metadata
```

---

### 6.3 Processor.py (Vision Pipeline)

**Purpose**: Image processing and QR analysis

**Key Responsibilities**:
```
├── Geometric Rectification
│   ├── Orientation → angles
│   ├── Build rotation matrix
│   ├── Project pixels to wall
│   └── Create rectified image
│
├── QR Detection
│   ├── YOLO-based detector
│   ├── Bounding box extraction
│   ├── Centroid calculation
│   └── ROI cropping
│
├── QR Enhancement
│   ├── Resize to 400x400
│   ├── CLAHE (contrast)
│   ├── Unsharp masking
│   └── Binary threshold
│
├── QR Decoding
│   └── WeChat QR detector
│
├── Coordinate Transformation
│   ├── UV → Camera frame
│   └── Camera → Global frame
│
└── Inventory Management
    ├── Payload parsing
    ├── Duplicate detection
    ├── CSV storage
    └── API posting
```

**QR Enhancement Pipeline**:
```
Input Image
    │
    ├─► Resize (400x400, LANCZOS4)
    │
    ├─► CLAHE (clipLimit=2.0, tileSize=8x8)
    │
    ├─► Unsharp Mask
    │     gaussian = GaussianBlur(σ=2.0)
    │     sharpened = 1.5*enhanced - 0.5*gaussian
    │
    ├─► Binary Threshold (threshold=140)
    │
    └─► WeChat QR Decoder
          └─► Payload String
```

---

### 6.4 servoBoard.py (Servo Driver)

**Purpose**: Low-level servo communication

**Key Features**:
```
├── Serial Communication (115200 baud)
├── Servo Commands
│   ├── move(id, angle)
│   ├── calibrate(id)
│   └── get_positions()
│
├── LED Control
│   ├── RGB + brightness
│   ├── Signal colors
│   └── Flash modes
│
└── Camera Helpers
    ├── set_camera_orientation()
    ├── servo_move_to()
    └── get_pose_list()
```

---

## 7. Complete Scanning Workflow Example

```
┌─────────────────────────────────────────────────────────────────┐
│  USER REQUEST: Scan shelf at (x=2.5m, y=1.0m) with TOP sweep   │
└──────────────────────┬──────────────────────────────────────────┘
                       │
                       ▼
        visionNode.capture(x=2.5, y=1.0, isTop=True, isBottom=False)
                       │
                       ├──► LED: Yellow (Scanning)
                       │
                       ├──► Move servo to (H=1, V=1)
                       │    Wait 250ms
                       │    Scanner.capture_best_frame()
                       │      ├─► Burst: 10 frames
                       │      ├─► Select sharpest
                       │      └─► Save: capture_2024-12-06_14-30-15.png
                       │    Queue job: {path, x=2.5, y=1.0, ori=1}
                       │
                       ├──► Move servo to (H=1, V=2)
                       │    Wait 250ms
                       │    Scanner.capture_best_frame()
                       │      └─► Save: capture_2024-12-06_14-30-16.png
                       │    Queue job: {path, x=2.5, y=1.0, ori=2}
                       │
                       ├──► Move servo back to (H=1, V=1)
                       │
                       └──► LED: Green (Complete)

            [Background Processor Worker processes queued jobs]

        FOR EACH QUEUED JOB:
            │
            ├─► Load image
            │
            ├─► Rectify to camera frame
            │     • orientation=1 → theta=90°, phi=90°
            │     • Project 640x480 → rectified image
            │
            ├─► Detect QR codes
            │     • YOLO finds 3 QR codes
            │     • Bounding boxes: [(x1,y1,x2,y2), ...]
            │
            ├─► FOR EACH QR:
            │     ├─► Enhance (CLAHE + Unsharp + Threshold)
            │     ├─► Decode: "R03_S2_ITM145"
            │     ├─► Parse: rack=R03, shelf=S2, item=ITM145
            │     ├─► Transform coordinates
            │     │     UV (320, 240) → Camera (0.05, 0.12)
            │     │     → Global (2.55, 1.12)
            │     │
            │     ├─► Check duplicates
            │     │     • Distance = 0.03m < threshold
            │     │     → IGNORE (already scanned)
            │     │
            │     └─► Next QR...
            │
            ├─► Decode: "R03_S3_ITM201"
            │     • Global coords: (2.57, 1.35)
            │     • No duplicates found
            │     → NEW ENTRY
            │     → Save to inventory.csv
            │     → POST to API
            │
            └─► Processing complete

        LED: Off (Idle)
```

---

## 8. Performance Characteristics

```
┌─────────────────────────────────────────────────────────────────┐
│                      TIMING ANALYSIS                             │
├─────────────────────────────────────────────────────────────────┤
│  Servo Movement:          ~250ms per angle change                │
│  Burst Capture:           ~330ms (10 frames @ 30fps)            │
│  Image Save:              ~50ms (PNG compression)                │
│  Queue Handoff:           ~1ms                                   │
│  ────────────────────────────────────────────────────────────── │
│  Single Capture Total:    ~630ms                                 │
│  Top Sweep (2 angles):    ~1260ms                                │
│  Full Sweep (3 angles):   ~1890ms                                │
│                                                                  │
│  Processing (per image):                                         │
│    - Rectification:       ~50ms                                  │
│    - QR Detection:        ~100ms                                 │
│    - QR Decoding:         ~80ms per QR                          │
│    - Coordinate transform: ~1ms                                  │
│    - Database update:     ~10ms                                  │
│  ────────────────────────────────────────────────────────────── │
│  Total (1 QR):            ~240ms                                 │
│  Total (3 QRs):           ~400ms                                 │
└─────────────────────────────────────────────────────────────────┘
```

---

## 9. Error Handling & Robustness

```
┌─────────────────────────────────────────────────────────────────┐
│                    ERROR HANDLING STRATEGY                       │
├─────────────────────────────────────────────────────────────────┤
│                                                                  │
│  Camera Failures:                                                │
│    → Try multiple device indices [0, 1, 2]                      │
│    → Verify frame capture before accepting camera                │
│    → Log all initialization errors                               │
│                                                                  │
│  QR Detection Failures:                                          │
│    → Return empty list (no crash)                                │
│    → Log "NO_QR_DETECTED" status                                 │
│    → Continue with next frame                                    │
│                                                                  │
│  QR Decoding Failures:                                           │
│    → Enhancement pipeline (3 stages)                             │
│    → Skip invalid payloads                                       │
│    → Log but don't block                                         │
│                                                                  │
│  Servo Failures:                                                 │
│    → Graceful degradation (continue without servo)               │
│    → Log warnings                                                │
│    → Manual control still available                              │
│                                                                  │
│  Network Failures (API POST):                                    │
│    → Log error                                                   │
│    → Continue processing (local CSV preserved)                   │
│    → Retry logic can be added                                    │
│                                                                  │
│  Duplicate Detection:                                            │
│    → Normalized Euclidean distance                               │
│    → Configurable thresholds (x: 0.5m, y: 0.5m)                │
│    → Same item, new location → New entry                         │
│                                                                  │
└─────────────────────────────────────────────────────────────────┘
```

---

## 10. Configuration Management

```yaml
# config/config.yaml

camera:
  d: 0.20                    # Distance to wall (meters)

scanner:
  camera_candidates: [0, 1, 2]
  image_width: 640
  image_height: 480
  fourcc_codec: "MJPG"
  fps_target: 30
  servo_port: "/dev/ttyUSB0"
  servo_baud_rate: 115200
  enable_servo: true
  raw_save_dir: "data/raw_captures"

processor:
  log_file: "data/logs/processor.log"
  inventory_file: "data/inventory.csv"
  raw_meta_csv: "data/raw_captures/metadata.csv"
  save_annotated: false

duplicacy_thresholds:
  x: 0.5                     # 50cm horizontal
  y: 0.5                     # 50cm vertical

qr_detector:
  conf_th: 0.5               # YOLO confidence
  nms_iou: 0.45              # Non-max suppression
  padding_value: 0.3         # ROI padding (30%)

session:
  session_id: "S001"
  session_url: "http://api.warehouse.com/inventory"
```

---

## 11. Key Algorithms

### 11.1 Sharpness-Based Frame Selection
```python
def compute_sharpness(frame):
    gray = cv2.cvtColor(frame, cv2.COLOR_BGR2GRAY)
    laplacian = cv2.Laplacian(gray, cv2.CV_64F)
    return laplacian.var()  # Higher = sharper
```

### 11.2 Normalized Distance for Duplicates
```python
def check_distance(coords1, coords2, threshold_x, threshold_y):
    dx = coords1[0] - coords2[0]
    dy = coords1[1] - coords2[1]
    
    # Normalized Euclidean distance
    norm_dist = sqrt((dx/threshold_x)² + (dy/threshold_y)²)
    
    return norm_dist <= 1.0  # True if duplicate
```

### 11.3 Camera Ray Intersection
```python
def uv_to_camera_coords(u, v, K, R, d):
    # 1. Get camera ray
    ray_cam = [(u - c_x)/f_x, (v - c_y)/f_y, 1.0]
    
    # 2. Rotate to world frame
    ray_world = R @ ray_cam
    
    # 3. Intersect with plane at distance d
    t = d / ray_world[1]
    x_cam = t * ray_world[0]
    y_cam = t * ray_world[2]
    
    return (x_cam, y_cam)
```

---

## 12. System States

```
┌─────────────────────────────────────────────────────────────────┐
│                     SYSTEM STATE MACHINE                         │
├─────────────────────────────────────────────────────────────────┤
│                                                                  │
│  IDLE                                                            │
│    ├─► Camera: Active                                           │
│    ├─► Servo: Neutral (H=1, V=1)                               │
│    ├─► LED: Off                                                 │
│    ├─► Queue: Empty                                             │
│    └─► Processor: Waiting                                       │
│                                                                  │
│  SCANNING                                                        │
│    ├─► Camera: Capturing                                        │
│    ├─► Servo: Moving between angles                            │
│    ├─► LED: Yellow (warning)                                    │
│    ├─► Queue: Jobs pending                                      │
│    └─► Processor: Active                                        │
│                                                                  │
│  PROCESSING                                                      │
│    ├─► Camera: Idle                                             │
│    ├─► Servo: Neutral                                           │
│    ├─► LED: Blue (working)                                      │
│    ├─► Queue: Draining                                          │
│    └─► Processor: Active (background)                           │
│                                                                  │
│  COMPLETE                                                        │
│    ├─► Camera: Idle                                             │
│    ├─► Servo: Neutral                                           │
│    ├─► LED: Green (success)                                     │
│    ├─► Queue: Empty                                             │
│    └─► Results: Saved to CSV + API                             │
│                                                                  │
│  ERROR                                                           │
│    ├─► Camera: May be released                                  │
│    ├─► Servo: Safe position                                     │
│    ├─► LED: Red (danger)                                        │
│    ├─► Queue: Flushed                                           │
│    └─► Logs: Error details written                             │
│                                                                  │
└─────────────────────────────────────────────────────────────────┘
```

---

## Summary

This is a **production-grade computer vision system** for warehouse inventory management. The architecture features:

✅ **Modular Design**: Clear separation of hardware, processing, and orchestration  
✅ **Robustness**: Multi-level error handling and graceful degradation  
✅ **Performance**: Background processing with multiprocessing  
✅ **Accuracy**: Multi-stage QR enhancement and geometric rectification  
✅ **Scalability**: Queue-based job distribution  
✅ **Maintainability**: Comprehensive logging and configuration management

The system successfully bridges the gap between physical hardware (camera, servos, LEDs) and digital inventory management (CSV database, REST API) through sophisticated computer vision and coordinate transformation pipelines.

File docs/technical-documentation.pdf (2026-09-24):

## Inter IIT Tech Meet 14.0

### Mid Prep Event

# Autonomous Rover for

# Warehouse Rack Inventory Management

## End Term Documentation

### Team ID: 27

### Date: December 6, 2025

# Contents

1 Executive Summary | 4
2 Problem Understanding & Motivation | 6
3 System Architecture | 7
4 Hardware Design | 15
5 Software Architecture | 19

6 Integration & Control | 33
7 Testing & Validation Summary | 35
8 Innovation & Novel Contributions | 37
9 Limitations & Future Scope | 40
10 Innovation Highlights | 41
11 Testing & Validation | 43

11.3 Image capture | 43
11.4 Navigation | 44
12 Maintenance | 46
12.1 Preventive Maintenance | 46
12.2 Replacement Parts | 46
12.2.1 Electrical and Control Units | 46
12.2.2 Mechanical Structures | 47
12.3 Storage and Transport | 47
13 References & Appendix | 48

# List of Figures

2.1 Overview of key operational stages in warehouse logistics. Source: https://
anchanto.com/wms-robotics-for-efficient-warehouse-operations/ . . . . | 6
3.1 High level interaction between the rover’s hardware subsystems and software stack. . | 7
3.2 Block diagram of the robot’s navigation and control hardware architecture | | 7
3.3 Power distribution diagram for battery, buck converters, and controllers | | 9
3.4 Software pipeline from sensors and vision node to SLAM, Nav2, and motor control. . 10
3.5 Complete Vision Pipeline from raw image to data logging | 11
3.6 Block diagram of the Human Machine Interface | 11
3.7 Interface of website | 12
3.8 Block diagram of the Data flow from the sensors to the HMI | 14
5.1 Mapping Using SLAM | 22
5.2 High level architecture of Vision Pipeline | 23
5.3 We use the above three coordinate frames to establish a 3D projection of image to
a plane parallel to the rack (Geometric Rectification) | 27
5.4 QR code processing pipeline from projected image to inventory records | 28
5.5 Real-time warehouse inventory dashboard showing rack status, search, and event logs 30
11.1 QR code processing pipeline from projected image to inventory records | 43
11.2 QR code processing pipeline from projected image to inventory records | 43
11.3 Inventory.csv | 44
11.4 Inventory.csv | 44
11.5 Map generation via Nav2 and SLAM | 45

# Chapter 1

# Executive Summary

## 1.1 Problem Statement

Modern high output warehouses operate with tightly coupled Warehouse Management Systems and fast pick and pack workflows, yet the ground truth on the racks often drifts away from what the database reports. Inventory updates are typically driven by manual cycle counts and operator scans, which introduce latency, human error and inconsistent coverage, particularly for higher rack levels and densely packed locations. This mismatch between the inventory state and the physical stock layout directly affects fulfillment reliability, slotting efficiency, and overall output.

To close this gap, we target a compact, battery–powered autonomous mobile robot that can drive through standard warehouse aisles, scan vertical rack faces up to about 2 m in height, and capture clear visual and QR–code data for every storage location. The rover is expected to work safely around people and existing equipment, and to deliver consistent, measurable performance that is suitable for real operational use.

Concretely, the system is required to:

- Navigate and align with racks with horizontal accuracy better than ±10 cm, and position its
| camera vertically within ±2 cm of the target level.
- Complete a full scan of a 1.8 m rack segment in under 3 minutes, using images with a resolution
| of 1920×1080.
- Reliably detect and decode 5 cm×5 cm QR codes with a success rate above 90% and maintain
| scanning repeatability above 95%.
- Operate within defined safety limits, including obstacle detection, collision avoidance, and an
| emergency stop that can bring the robot to a halt in under 500 ms.
1.2 | Solution Summary

This work introduces an Autonomous Mobile Robot (AMR) specifically designed to carry out rackface inventory verification. The rover drives itself through the aisles, aligns in front of a selected bay, and uses a vertical motion stage to position a camera at each storage level. At every stop, it reads QR codes attached to locations and links them to precise spatial coordinates within the warehouse.

The core idea is to treat the rack face as an active sensing surface. The rover combines horizontal navigation, vertical positioning, and on-board perception to maintain a structured digital representation of rack locations. Inventory verification is executed as short, repeated passes over selected rack segments rather than occasional full manual counts.

At a high level, the system is designed to achieve the following capabilities:

- Autonomous aisle navigation: Navigate between rack bays within a structured warehouse
| map without continuous human supervision.
- Rack-level positioning: Position the camera at variable rack heights using a controlled
| Z-axis mechanism that maintains alignment with the storage levels.

- Label acquisition and decoding: Detect and decode QR codes or location labels under typical indoor warehouse lighting and viewing distances.
- Spatially anchored records: Associate each decoded label with a specific physical location and time stamp so that observations can be integrated into a persistent digital rack model.

The system is engineered for deployment in real warehouse environments. The rover integrates mechanical, electrical, and software subsystems around a focused warehouse use case and is built primarily from commercially available components and open-source tools to keep the design maintainable, serviceable, and reproducible across sites.

## 1.3 Key Metrics and Innovation Highlights

The overall aim of the project is to deploy an autonomous system for reliable rack-level inventory verification in operational warehouse environments. The main technical objectives are:

- Reliable navigation in aisles: Develop a mobile base that can localise itself within a
| structured warehouse map and follow planned paths in narrow aisles with sufficient accuracy to align its camera with the front of the racks.
- Controlled vertical scanning: Design and implement a Z-axis mechanism that can move
| the camera smoothly from floor level up to around 1.8 m, stopping at well-defined scan heights that correspond to rack levels, while keeping vibration low enough to obtain clear images.
- Robust data capture: Build a perception pipeline that can reliably detect and decode QR
| codes at rack positions under typical indoor lighting and viewing distances, and update the inventory record with a repeatability better than 95% over repeated runs.
- Integrated safety behaviour: Incorporate obstacle detection and an emergency stop chain
| so that the rover reacts safely to people and objects in its path, and can recover to a known state after interruptions without requiring a full manual re-alignment of the mission.

These objectives are selected to align directly with practical warehouse constraints. If the robot cannot align with racks, cannot reach the required heights, or cannot be trusted to read labels accurately and behave safely, it does not address the underlying inventory problem, irrespective of the sophistication of the individual technologies involved.

# Chapter 2

# Problem Understanding & Motivation

Large modern warehouses often look well organised from the outside, but inside it is hard to keep the digital inventory in line with what is actually on the racks. Items are moved, partially picked, put back on the wrong shelf or mislabelled when operators are under time pressure. In most sites, people still walk the aisles with handheld scanners or clipboards and run cycle counts late at night or during low activity periods.

This manual approach does not scale well as operations grow. Its main limitations are:

- High reliance on physical labour: A lot of staff time goes into repetitive, low value counting work.
- Increased risk of errors: Tired or rushed operators are more likely to skip locations or record wrong quantities.
- Safety and ergonomics issues: Workers often reach into high or awkward rack positions to verify stock.
- Out of date information: By the time counts are completed and entered, records often lag behind the real state of the racks.

Managers then have to make decisions based on records that do not always match what is physically present. The gap between the Warehouse Management System (WMS) and the actual inventory becomes a constant source of inefficiency and slowly reduces trust in the system.

Our work is driven by this gap. We focus on one clear question that every warehouse needs to answer with confidence: what is stored at each rack location, right now? Instead of adding more people to do more counting, we explore whether a compact autonomous system can perform this verification task automatically, in a continuous and repeatable way.

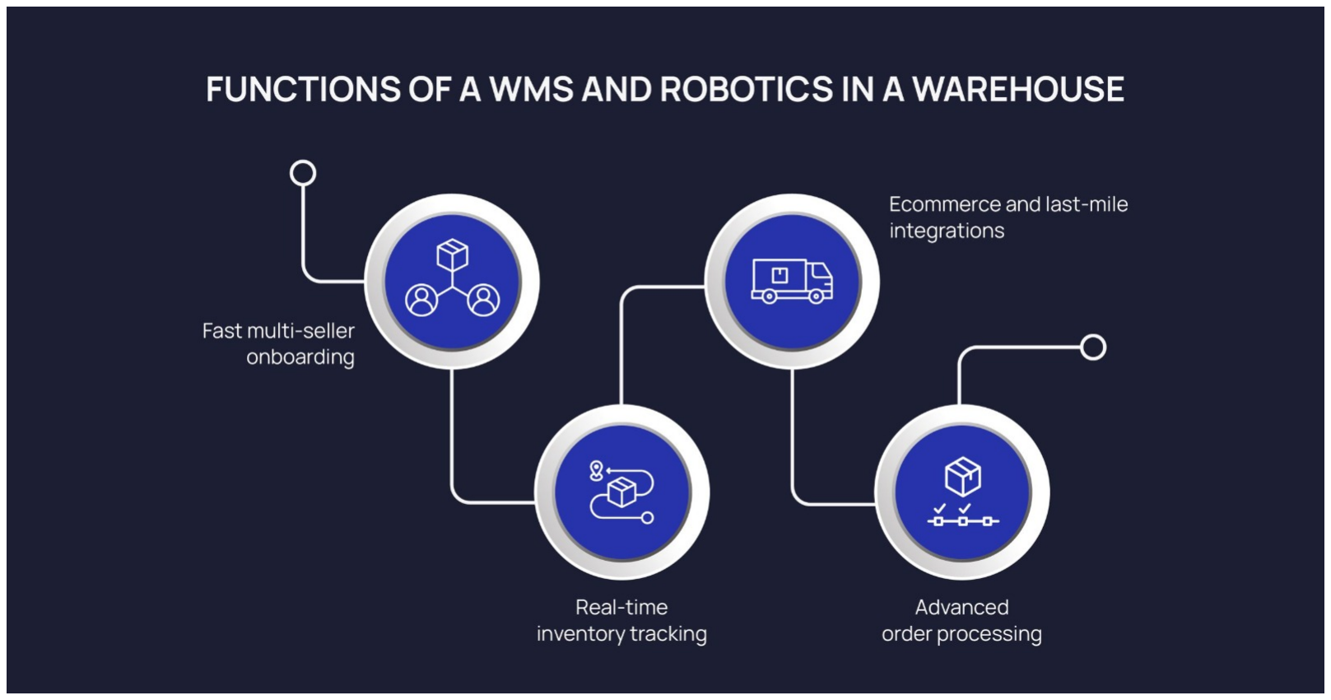
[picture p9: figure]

Figure 2.1: Overview of key operational stages in warehouse logistics.
Source: https://anchanto.com/wms-robotics-for-efficient-warehouse-operations/

# Chapter 3

# System Architecture

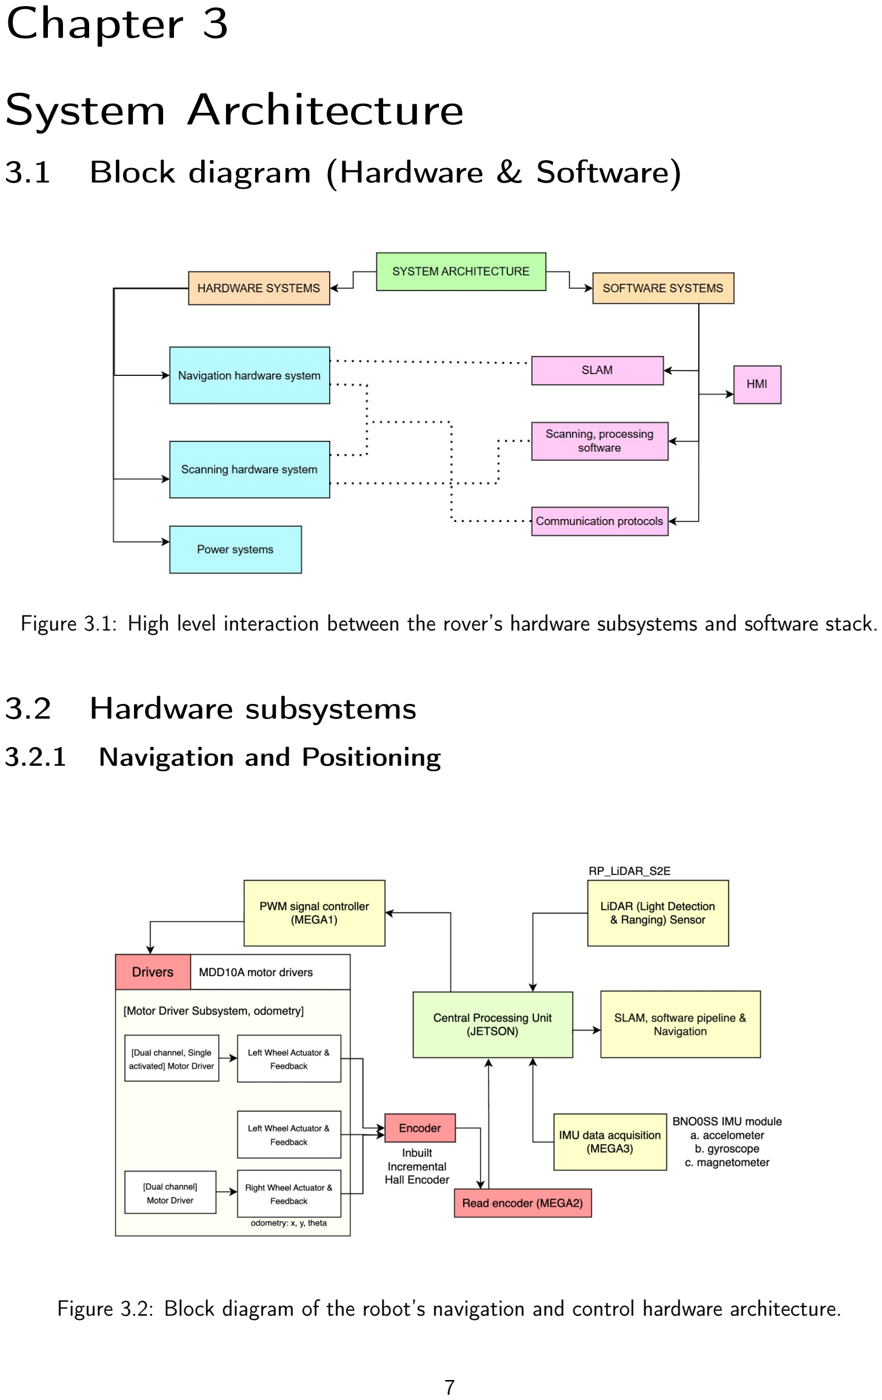
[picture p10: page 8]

## 3.1 Block diagram (Hardware & Software)

Figure 3.1: High level interaction between the rover’s hardware subsystems and software stack.

3.2 | Hardware subsystems
3.2.1 | Navigation and Positioning

Figure 3.2: Block diagram of the robot’s navigation and control hardware architecture.

X–Y Motion Subsystem

The X–Y motion subsystem is responsible for all movement in the horizontal plane. It uses a twowheel differential drive with one caster at the front and one at the back so that the robot can move forward, backward, and rotate on the spot inside narrow aisles.

- Actuators and drive: Two high-torque IG42 geared DC motors drive the main wheels on either side of the chassis. The wheels are HD-type with thick rubber grip to provide sufficient friction on smooth warehouse floors and to reduce slip during starts, stops, and turns.
- Encoders and closed-loop control: Each IG42 motor includes an integrated rotary encoder. The Arduino Mega reads these encoder signals and uses them to control the wheel speeds in closed loop. This allows the ≈ 25 kg robot to track commanded velocities reliably and to perform controlled rotations around its centre.
- Motor drivers and power interface: The drive motors are powered through a Cytron MDD10 dual-channel motor driver. The Arduino sends PWM and direction signals to the driver, and the driver supplies the required current to the motors. This separates power handling from control logic and keeps the motors within safe operating limits.
- Interface to the navigation stack: The Arduino computes odometry from the wheel encoders and sends it back to the Jetson Orin over the serial link. On the Jetson, the localisation and navigation modules fuse this odometry with data from the LiDAR, and IMU measurements that include linear acceleration, angular velocity, and yaw rate. This multisensor fusion forms a robust perception pipeline:
Encoder Odometry → IMU Motion Refinement → LiDAR Based Scan Matching → Final Position Adjustment + Estimation.
The resulting estimate is then used by the navigation stack to plan paths that respect the robot’s footprint, aisle geometry, and collision constraints.

Z Motion Subsystem

The Z motion subsystem is responsible for moving the camera vertically up and down, and scanning the QR codes in real time so that different rack levels can be scanned reliably.

- Actuation and transmission: Vertical motion is provided by a high-torque IG45 geared DC motor that drives a continuous timing belt. The belt runs over a set of pulleys and is fixed to the camera carriage. The pulley layout keeps the belt in a single plane, which reduces side loads on the guides and lowers the torque required from the motor.
- Direction of motion: Clockwise rotation of the IG45 motor drives the camera carriage downward, while counter-clockwise rotation moves it upward. The mapping between motor rotation and vertical travel is governed by the pulley diameter and belt pitch, and this relationship is used when computing precise target heights for each scan position. Additionally, the X-channel structural base provides lateral rigidity to the entire assembly, significantly reducing wobble during vertical motion and ensuring stable positioning at all rack levels.
- Motor driver and control interface: The IG45 motor is powered by a Cytron MDD10A motor driver. The Arduino Mega, same as the one used in drive, sends PWM and direction signals to this driver, following the same pattern as the X–Y drive. This keeps the control interface consistent across the motion subsystems.

- Z Position feedback: The IG45 motor includes an integrated encoder that provides position feedback. The encoder ticks are linearly mapped to the camera height. Based on experimental results, 163 encoder ticks correspond to 1 cm Z motion. This information is used by the scanning algorithm to obtain the position of the QR scanned.

### 3.2.2 Scanning

Camera unit

An IMX258 13MP OIS USB Camera module has been mounted on a carriage on the vertical mechanism, driven by the timing belt. The camera subsystem can further be divided into two parts – actuation and capture.

- Actuation – A couple of SC15 servo motors have been mounted on the carriage, providing two extra degrees of freedom to the camera module, allowing clear scans in case the camera is not able to reliably detect or interpret a QR code at the extreme ends of its FOV. These motors are controlled using Waveshare ESP32 servo expansion board which is also mounted on the carriage. This driver precisely controls and returns the position feedback of the two servos, effectively giving the exact position and orientation of the camera module.
- Capture – Once the servo motors and the vertical mechanism have stably reached the final position and orientation, the vision pipeline first detects and then scans the QR codes within its current FOV, giving the relevant output on the HMI.

### 3.2.3 Power

The following flowchart illustrates the power subsystem. It clearly indicates how the power is distributed from a centralised battery pack to every subsystem. The battery supplies power parallely to four power rails– A 7V power rail powered through a 12-7 step down buck converter to power the arduino megas and the servo driver, a stable 12V rail powered by another 12-12 buck converter to power jetson orin and LiDAR, and two 12V rails directly from the battery, secured by a 10A fuse to power the motor drivers.

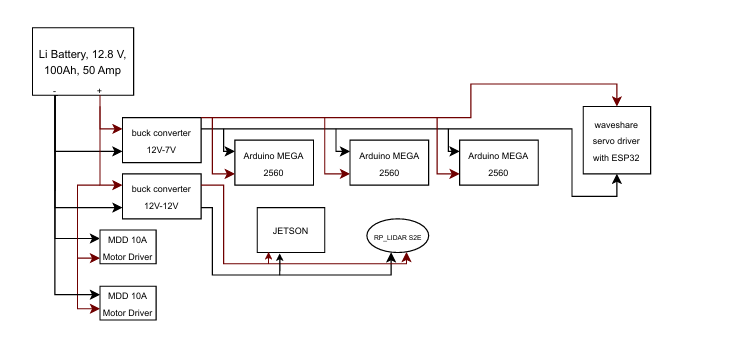
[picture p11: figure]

Figure 3.3: Power distribution diagram for battery, buck converters, and controllers.

3.3 | Software Stack
3.3.1 | SLAM

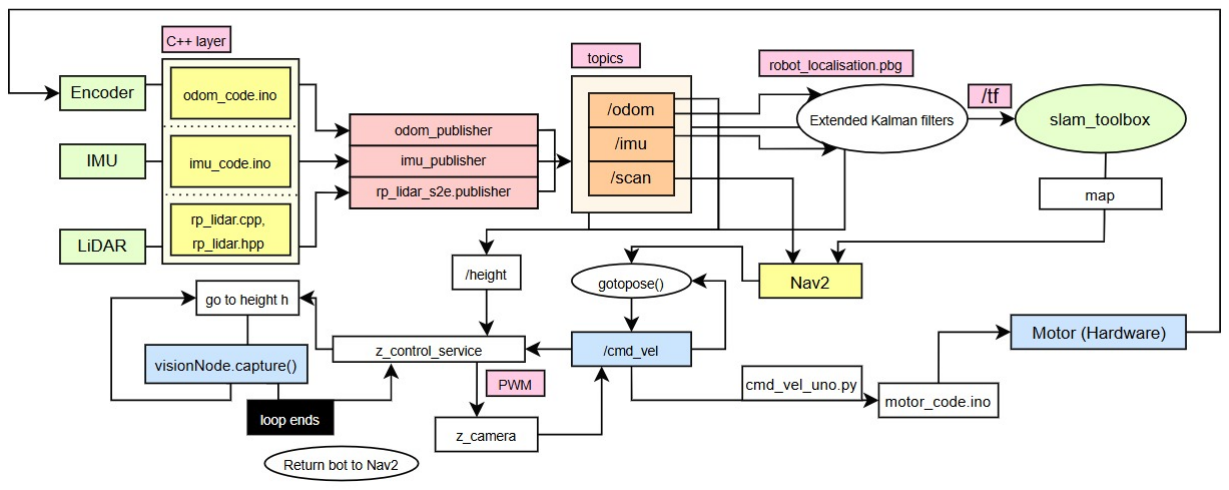
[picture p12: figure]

Figure 3.4: Software pipeline from sensors and vision node to SLAM, Nav2, and motor control.

Simultaneous Localisation and Mapping (SLAM) allows the rover to build a map of the warehouse while at the same time and position estimating its own pose inside that map. Using only onboard sensors, the system observes surrounding walls and racks, tracks how the base moves, and produces a 2D occupancy grid that represents free, unknown and occupied space.

On this robot, SLAM Toolbox performs this task by consuming LiDAR scans together with IMU and wheel odometry information. As the rover moves, the node incrementally updates the map and corrects drift by aligning new scans with previous ones using robot_localisation which fuses data of the two sensors that is odometry and IMU. The resulting map and pose estimate are then used by the Nav2 stack as the global reference for path planning, obstacle checking and repeated autonomous missions.

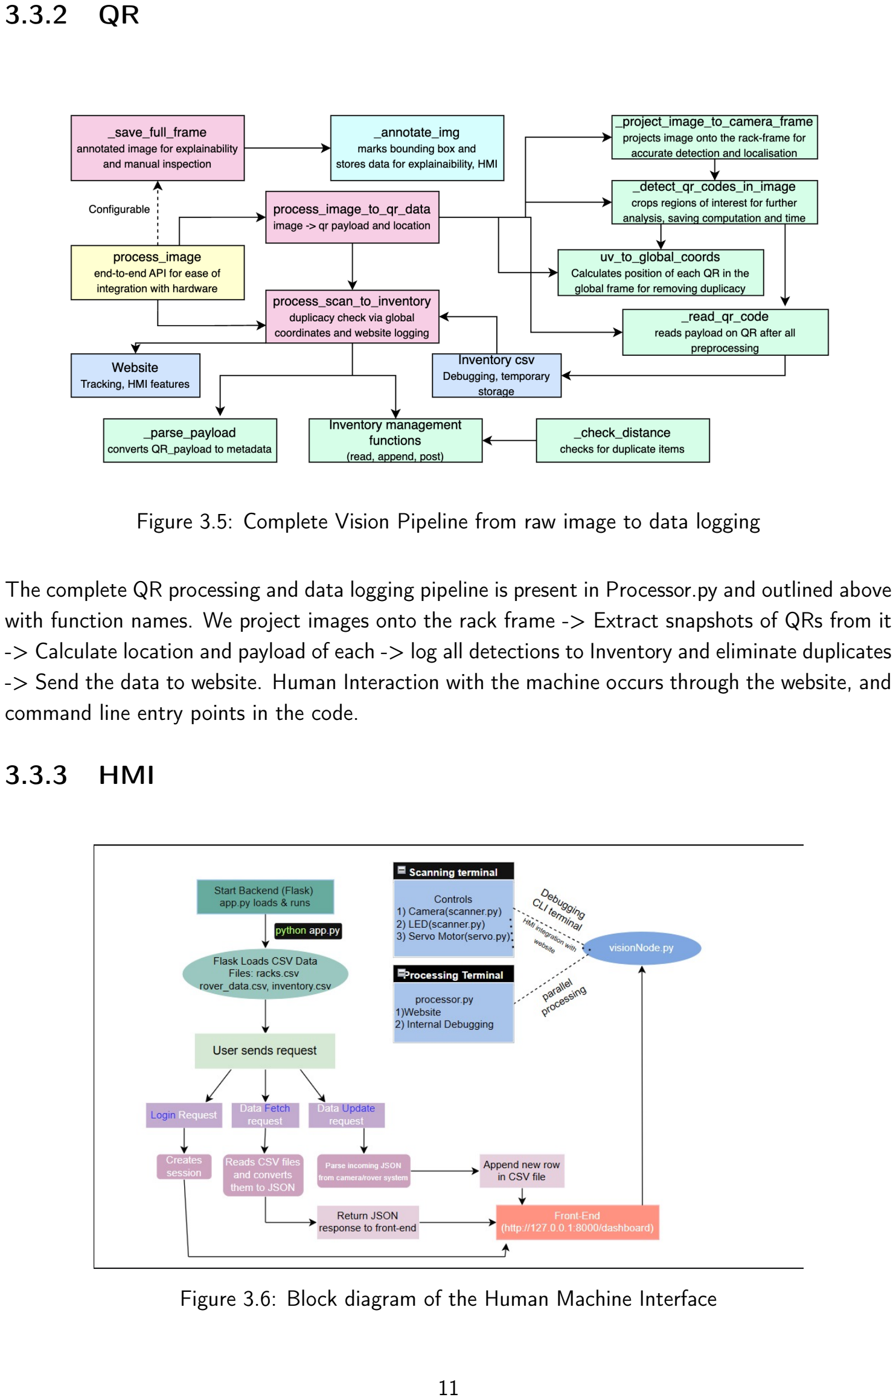
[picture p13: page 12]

3.3.2 QR

Figure 3.5: Complete Vision Pipeline from raw image to data logging

The complete QR processing and data logging pipeline is present in Processor.py and outlined above with function names. We project images onto the rack frame -> Extract snapshots of QRs from it -> Calculate location and payload of each -> log all detections to Inventory and eliminate duplicates -> Send the data to website. Human Interaction with the machine occurs through the website, and command line entry points in the code.

### 3.3.3 HMI

Figure 3.6: Block diagram of the Human Machine Interface

Website Interface

The human machine interface (HMI) for the rover is implemented as a small web application that runs on top of the core ROS 2 navigation and perception stack. The HMI has two main roles:

- provide operators with a live view of rack states, robot status, and recent scans, and
- expose a simple control surface for starting, stopping and monitoring runs without logging into the robot over SSH.
- manually control the movements of the camera precisely to enhance field of view of the scanning process

The web application is built from two HTML templates, login.html and dashboard.html. The login page restricts access to authorised users. After successful authentication it redirects to a dashboard that shows a list of rack cards, each card displaying the shelf identifier along with the code of the item present in the shelf. The event logs in below the live rack keeps track of all the scanning activities and motion of the bot along with the corresponding timestamp.¹

The back end is a Python Flask service that runs in a separate backend folder. A single file app.py holds the Flask application, session based authentication logic, CSV parsing functions and HTTP endpoints for the dashboard. The service reads and updates three CSV files: rover_data.csv for telemetry, racks.csv for rack metadata and inventory.csv for inventory records. These CSV files act as a light data store for the HMI and keep the web layer independent of the ROS 2 log formats.²

At run time the perception nodes write scan results and inventory events into the CSV files. The Flask back end normalises these entries and serves them as JSON to the dashboard, which periodically requests updates. In this way the HMI stays in sync with the robot without affecting the timing of the core navigation and scanning pipelines.

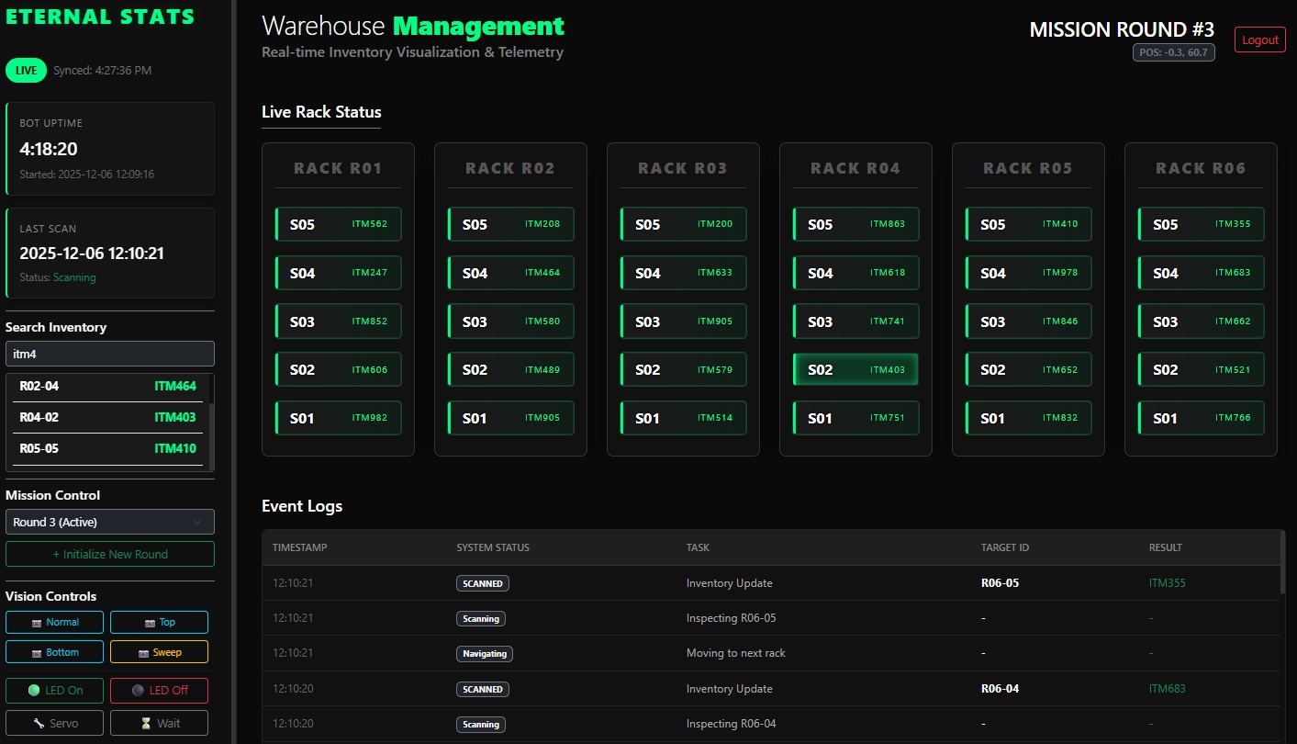
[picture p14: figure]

Figure 3.7: Interface of website

1Front end and back end structure follow the separate website documentation supplied with the project. 2Backend organisation and file layout are taken from the website documentation.

Command Line Interface

Along with the web dashboard, a light command line interface is provided for developers and maintenance staff. It exposes a few focused tools that help in debugging, parameter tuning and checking the health of the vision hardware.
- save_annotated_image flag: A flag in compile.yaml lets the user enable saving of annotated images. When it is set, the pipeline stores projected frames with QR boxes, confidence scores and basic metadata at a user specified path. These images are used to see what the detector is actually picking up and to tune model thresholds for a given warehouse.
- Servo angle display and return_to_home: A small utility prints the current angles of the pan and tilt servos that control the camera. The code also exposes a return_to_home helper where an operator can record the neutral values of Servo[0] and Servo[1]. At the end of a session the camera is sent back to this neutral pose, which compensates for mechanical drift over time and keeps the motion range within safe limits.

## 3.4 Data flow diagram

The data path from sensors to the HMI proceeds in two main streams. Encoder, IMU and LiDAR signals are first read by the motor and sensor controllers, which send compact messages to the Jetson. On the Jetson, ROS 2 nodes convert these messages into the /odom, /imu and /scan topics. These topics are fused by the state estimation node and passed to slam_toolbox, which maintains the 2D map and provides the robot pose that is used by the navigation stack. The same pose and velocity commands are forwarded to the Arduino MEGAs that drive the base and lift motors.

In parallel, the camera stream is processed by the vision node. For each scan request it captures an image, runs the QR detection and decoding pipeline, and writes the decoded item ID together with rack, shelf and global coordinates into an inventory table. A lightweight Python back end reads this table, exports it as JSON, and serves it to the web based HMI. The HMI dashboard then presents live rack status and a log of scan events to the operator.

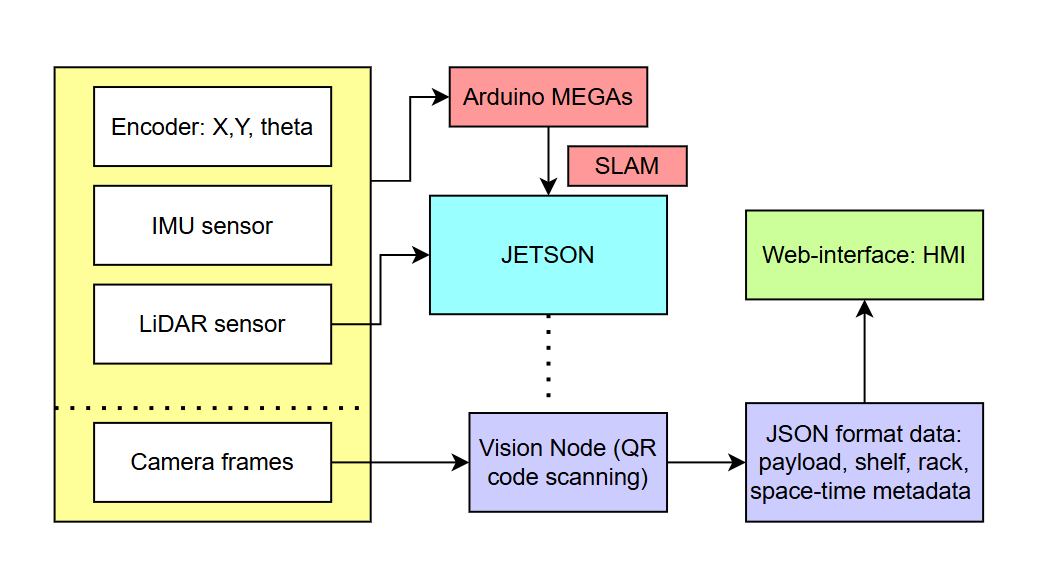
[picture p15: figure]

Figure 3.8: Block diagram of the Data flow from the sensors to the HMI

# Chapter 4

# Hardware Design

## 4.1 Chassis Specifications

The mechanical layout of the base is designed around a compact footprint and stable support for the X–Y and Z motion subsystems.

- Footprint and support: The chassis is dimensioned to stay within the 600 mm × 450 mm
| constraint while carrying the full system mass of approximately 25 kg. Two drive wheels are mounted on the sides and two casters are placed at the front and rear, giving a four-point support that spreads the load and maintains stability.
- Commodities and raw material selection: The base plate has been fabricated using a
| 3 mm aluminium plate to provide the required strength to bear the load of the 25 Kg bot. All other plates have been fabricated using 3 mm acrylic to reduce the total weight of the bot. The plates are supported using 2020 aluminium extrusions, which have low density, high tensile and compressive strength, and high durability. M5 fasteners have primarily been used in most of the joints. M4 and M3 fasteners have been used wherever necessary in case of mounts and hubs. Mild steel shafts have been used for rotatory components to ensure stability and sturdiness to the bot as many of these are meant to bear very high load.
- Safety oriented chassis geometry: The chassis has been designed keeping in mind ISO
| and RIA standards. The base plate has been thoroughly chamfered to avoid any tips or pointed edges. All the edges have been covered by aluminium extrusions having smooth edges to even further enhance the safety of the people around the bot.
4.2 | Drive System
- Differential drive geometry: The drive wheels and omni casters are positioned so that
| the centre of rotation lies close to the geometric centre of the robot. This allows the base to rotate almost in place inside an aisle without the corners moving outside the permitted clearance near the racks.
- Drive wheel selection and floor interaction: The powered wheels are HD-type wheels
| with rubber grips. The combination of wheel diameter, tread material and motor torque is chosen to provide reliable traction on smooth warehouse floors while keeping vibration and slip low during starts, stops and turns.
- Omni wheel selection: Two omni wheels, one at the front and one at the back, act as
| stabilizers. They are mounted on 8 mm shafts with bearings and maintain consistent contact with floor, keeping the robot balanced in all directions. Their diameter matches that of the drive wheels, ensuring all four wheels share the load and remain in contact with ground.
- Motor control unit: The motor control unit connects the Arduino Mega PWM and direction
| pins to two Cytron MDD10A motor drivers. The Jetson sends velocity and Z-axis position commands over serial, and the Mega converts these into PWM signals that drive the IG42 differential base motors and the IG45 Z-axis actuator.

## 4.3 Vertical Lift Mechanism

The Z-axis mechanism provides the structural and actuation system for the vertical motion of the camera and scanning assembly.

- Belt–pulley layout: The camera carriage runs on a rigid vertical frame with guided rollers
| for stable, repeatable motion. A continuous timing belt operates in a single plane over three pulleys (motor, top idler, in-line idler), minimising twist, side loads, and uneven tension.
- Load distribution and torque reduction: The single-plane belt routing limits off-axis
| forces and improves mechanical efficiency, reducing motor torque and power consumption. A long bolt functions as a passive idler to maintain uniform belt tension across the entire stroke.
- Constant pull mechanism: The belt arrangement ensures the carriage always experiences
| a controlled driving force in both upward and downward directions, improving reliability com- pared to friction-dependent belt systems.
- Motion characteristics: Pulley diameters and belt pitch define the conversion between
| motor rotation and vertical travel. These parameters establish discrete scan heights in software and guarantee full coverage from floor level to the highest rack position.
- Structural stiffness: The belt, pulleys, and carriage are mounted on aluminium extrusion
| profiles fastened at multiple points on the base, providing the rigidity required to minimise deflection, maintain rack alignment, and ensure consistent imaging.
- Constant stable actuation: Due to the rigidity of the Z-axis assembly, closed-loop control is
| unnecessary. A constant PWM drives the motor until the target height is reached. Predefined positions based on camera FOV and rack geometry enable fast, stable vertical positioning with minimal computational load.
4.4 | Sensor Justification

The main control unit is an NVIDIA Jetson Orin Nano running the ROS 2 stack for localisation, mapping, planning and scanning. Arduino Mega 2560 boards and an ESP-based servo controller handle direct hardware control, with commands and feedback exchanged over UART.

### Feedback Units

The feedback electronics are organised into three functional units:
- IMU unit: Interfaces a BNO055 absolute orientation sensor to an Arduino Mega over I²C.
| This 9-DoF sensor provides highly accurate orientation and acceleration data. Unlike other IMU modules, BNO055 consists of onboard sensor fusion, directly generating quaternions, eliminating the need for an external filter. The Mega reads the IMU metadata and forwards quaternion, accelerometer and gyroscope data to ROS 2 nodes on the Jetson via serial com- munication.
- Odometry unit: Connects the incremental encoders of the X, Y and Z drive motors to
| digital inputs on an Arduino Mega through interface pins. Motors with inbuilt encoders have specifically been used, primarily to save space and reduce the need for external encoders. Moreover, they require less power and since they need not be externally mounted or coupled to the motor shaft, they provide accurate motor shaft rotation and odometry data. The encoder counts are converted into drive and lift odometry and sent to the navigation stack as position and orientation estimates.
- LiDAR unit: Scans the surroundings using a 360-degree laser sweep in the scanning plane. The RPLiDAR S2E provides a range of upto 30 m radially with a sampling frequency of over 10 KHz, ideal for a warehouse or dark store. It has also got an eye-safe laser, providing a safe environment for workers working in proximity of the bot. Most importantly, it is connected to Jetson using Ethernet instead of conventional USB communication, providing high bandwidth, less noise, easy integration with ROS and ROS2, and significantly enhancing data transfer speed. The pointcloud generated is integrated with the odometry and imu readings using the SLAM toolbox to create a well-defined map of the surroundings.

The ESP based servo controller drives the pan–tilt camera mount. The Jetson Orin sends orientation targets, and the ESP converts these targets into low level servo commands that move the camera to the desired pose.

This architecture keeps high level decisions on the Jetson Orin Nano and delegates timing sensitive drive, encoder and sensor handling to microcontroller based units.

### Vision and Sensing Units

The vision and sensing layer combines the SC15 servo bus and the main camera module to give stable pointing and reliable image capture for the QR pipeline.

- SC15 position feedback: The SC15 bus servo provides angle and load feedback through its own encoders. It holds position with minimal backlash and good repeatability, which keeps the camera pose stable while frames are captured.
- Camera module: The camera has optical image stabilisation, a wide horizontal and vertical field of view and hardware autofocus (not used in our current setup). It connects over USB, which works well for longer cable runs inside the robot. The module is compact and light, and integrates cleanly with the Jetson Orin Nano for real time processing.

## 4.5 Power Systems

The PDB routes power from the main 12.8 V battery to the subsystems and generates separate regulated rails for compute, control, sensing and feedback devices.

- Battery input: A 12.8 V nominal battery feeds the PDB. The wiring and connectors on
| this input are rated for up to 50 A continuous current, covering expected peaks during base acceleration and Z-axis motion.
- High-current motor branch: The two Cytron MDD10A motor drivers (for the IG42 base
| motors and the IG45 Z-axis motor) are supplied directly from the 12.8 V battery bus through a series fuse.
- Logic and servo rail (7 V buck): A 12 A DC–DC buck converter generates a regulated
| 7 V rail for low-voltage control electronics: – three Arduino Mega boards for motion control and I/O, – one ESP-based servo controller for the pan–tilt unit, and – auxiliary loads such as the IMU and status indicators via 5 V / 3.3 V regulators.
- Compute and sensing rail (12 V buck): A second 12 A buck converter provides a regulated 12 V rail for the Jetson Orin Nano and the 2D LiDAR. This branch is protected by a series fuse sized for an expected combined current of up to 2 A.
- Load summary by rail: Table 4.1 summarises the main power rails and their associated loads.

Table 4.1: Power rail summary on the PDB

Rail | Nominal rating | Primary loads
Battery bus 12.8 V, up to 50 A 2 × Cytron MDD10A motor drivers (IG42 base motors, IG45
| | Z-axis motor)
Buck 1 | 7 V, 12 A | 3 × Arduino Mega, 1 × ESP servo controller, IMU, status
| | LEDs/buzzer
Buck 2 | 12 V, 12 A | Jetson Orin Nano, LiDAR (via fused branch, ≤2 A typical)

All high-current paths (battery to PDB, PDB to motor drivers and PDB to buck converters) are fused and use appropriately sized conductors and crimped terminals. Logic, encoder and compute grounds are tied to the main power ground at a single reference point on the PDB to limit ground loops and reduce noise on sensor and communication lines.

## 4.6 Safety Features

Safety features are built into the motion architecture at both hardware and software levels.

- Controlled speeds and torques: Wheel and lift commands are limited in software to stay within safe velocity and acceleration bounds, reducing the risk of instability when the robot rotates in place or when the Z-axis is near its upper positions.
- Closed-loop monitoring: Encoders on the X–Y motors allow the controller to detect deviations from expected motion, such as stalls or unexpected resistance.
- Z motion limits: Physical limit switches have been attached at the top and bottom of the vertical rail which prevent overextension of the camera carriage beyond desired limits. Set in the NC configuration, these switches break the motor circuit when pressed.
- Integration with higher-level safety logic: The Jetson Orin applies motion constraints based on obstacle detection, mission state, and safety inputs. The robot includes emergencystop buttons on the both sides, completely complying with the ISO standards. It has also got status LEDs and an active buzzer for bot status and warnings.
- Motion enforcement: The low-level controller monitors safety peripherals and enforces ISO-aligned operational rules, including speed limits in shared zones, controlled deceleration near humans, and mandatory halts on critical faults. When the perception layer detects a safety event, the Jetson Orin issues an immediate stop or restriction command, which the Arduino applies deterministically through the motor drivers.

# Chapter 5

# Software Architecture

## 5.1 Navigation Pipeline

The navigation pipeline is a ROS 2 based stack that converts raw sensor data into safe velocity commands for the base. It is organised into four stages:

- perception and state estimation,
- SLAM and global map building,
- path planning and local control,
- obstacle avoidance and recovery behaviours.

Perception combines 2D LiDAR, IMU and wheel odometry. An Extended Kalman Filter (EKF) fuses IMU and encoder data to provide a smooth estimate of pose and velocity in the odom frame. SLAM uses this estimate and the LiDAR scans to build a 2D occupancy map in the map frame. Nav2 then plans and executes motion using the map, the current pose and live costmaps. All components communicate through ROS 2 topics, services and TF transforms such as map, odom, base_link and laser.

### 5.1.1 SLAM

The SLAM module maintains a consistent 2D map of the environment while estimating the robot pose in that map.

### Sensors and inputs

- LiDAR: publishes 2D laser scans on /scan.
- IMU: publishes orientation and angular velocity on /imu.
- Wheel odometry: publishes integrated pose from encoders (for example on /odom/wheel).
- EKF node: fuses IMU and wheel odometry into a filtered odometry estimate on /odom and maintains the odom to base_link transform.

### SLAM Toolbox node

The async_slam_toolbox_node subscribes to the LiDAR scans on /scan and to the robot pose in the odom frame via TF. It incrementally builds a 2D occupancy grid map on the /map topic and can publish incremental updates on /map_updates. It also publishes the map to odom transform, correcting long term odometry drift through scan matching and loop closure.

TF frame chain.

The resulting TF tree has the form map → odom → base_link → laser, where:

- map → odom is provided by SLAM Toolbox,

- odom → base_link is provided by the EKF,
- base_link → laser is a static transform that encodes the LiDAR mounting pose.

At any time the global pose of the robot is obtained from the compound transform map → base_link, which is what Nav2 uses for planning. The map is built online as the robot moves. New areas are added and previous areas are refined when the robot revisits them.

### 5.1.2 Planning

Planning is handled by the ROS 2 Navigation2 (Nav2) stack. It converts high level goal poses into velocity commands that respect the global map and local obstacles.

### Inputs to planning

- Global map: occupancy grid from SLAM Toolbox on /map.
- Robot pose: obtained from the TF chain map to base_link.
- Sensor data: live LiDAR scans used to update global and local costmaps.
- Goal pose: a 2D pose in the map frame, set in RViz or by an external node.

### Global planning

The global planner computes a collision free path from the current pose to the goal using the global costmap. The path is represented as a sequence of waypoints in the map frame.

### Local planning

Nav2 incorporates its own internal PID style control inside the local planner. The local planner runs at a higher rate using a local costmap centred on the robot and:

- continuously computes heading and position error relative to the planned path and adjusts linear and angular velocities to correct these errors,
- scales the commanded speed based on path curvature, proximity to obstacles and dynamic limits defined in nav2_params.yaml,
- produces a stabilised velocity command (geometry_msgs/Twist on /cmd_vel) without requiring any external PID node.

This internal control loop performs the necessary regulation so that the robot tracks the planned trajectory smoothly while respecting safety and kinematic limits.

### Controller

Within Nav2 the closed loop control is handled by the local controller rather than by a separate PID node. The global NavFn planner first computes a path in the map frame using the A* algorithm instead of plain Dijkstra, which keeps the path length short while respecting the global costmap.

The local DWB controller then tries to follow this path by sampling velocity commands around the nominal cmd_vel and scoring them against the costmaps and kinematic limits. Because the real robot is not perfectly symmetric and the two drive motors do not reach exactly the same maximum speed, the base tends to deviate from the ideal trajectory. The DWB controller continuously evaluates the tracking error from odometry and selects the command that best reduces this deviation while remaining collision free. In practice this provides the role of a PID style stabilising loop, but fully integrated inside the Nav2 control layer.

### Behaviour tree coordination

Nav2 uses a behaviour tree to coordinate tasks such as computing the path to a pose, following the path and running recovery behaviours like clearing costmaps, rotating in place or replanning when the path is blocked.

### 5.1.3 Avoidance

Obstacle avoidance is configured through the nav2_params.yaml file, which sets how costmaps are built, how obstacles are inflated and how often the environment is refreshed. The behaviour is implemented through costmap layers, continuous sensor updates and the local planner.

Costmap layers.

Nav2 maintains two main costmaps:

- Global costmap: built from the SLAM map in the map frame.
- Local costmap: a robot centred costmap that is updated at a higher rate from live LiDAR data.

Both costmaps use layered plugins:

- Static layer: loads the occupancy grid produced by SLAM Toolbox.
- Obstacle layer: inserts and clears obstacles based on incoming LiDAR scans.
- Inflation layer: expands obstacle cells to create a safety margin around the robot footprint.

Online obstacle detection.

The LiDAR sensor continuously publishes laser scans on /scan. These scans update the obstacle layer in the local and global costmaps. Free space is marked when beams reach the background, and occupied cells are marked when returns are received from objects. As a result the costmaps reflect the current layout of racks, walls and temporary obstacles.

Reactive avoidance.

The local planner reads the live local costmap and generates /cmd_vel commands that:

- steer the robot away from cells with high cost that correspond to obstacles,
- adjust linear and angular velocity as the robot approaches obstacles,
- follow the global path while maintaining a safe clearance.

If no feasible command can be found, the behaviour tree triggers recovery actions such as rotating to rescan the area, clearing costmaps and requesting a new global path from the current pose.

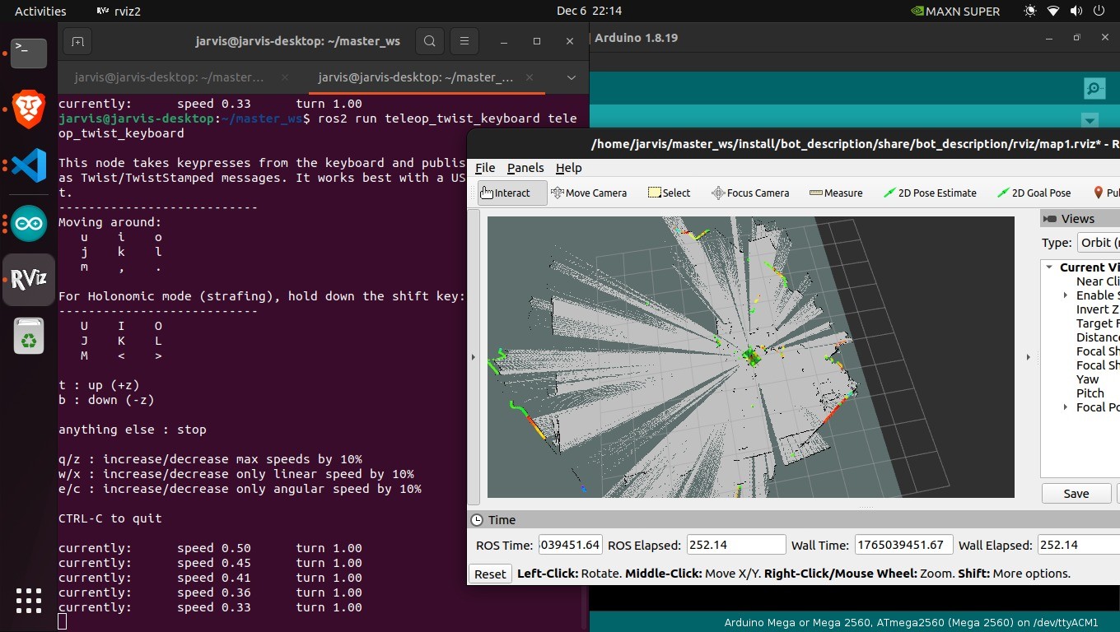
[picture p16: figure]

Figure 5.1: Mapping Using SLAM

## 5.2 Vision Pipeline

The vision subsystem forms the core of our warehouse inventory workflow. It performs real-time detection, decoding, and localization of QR codes(and hence the Items) placed on shelves, enabling the robot to map inventory items into a global coordinate frame integrated with the SLAM module.

The complete scanning pipeline spans hardware, software orchestration, multiprocessing data flow, and a structured output layer. A high-level breakdown is presented below.

### 5.2.1 High-Level System Architecture

The vision stack follows a modular design with three layers:

- Hardware Layer Physical sensing and actuation responsible for capturing multi-angle images and indicating system state.
- Software Layer (Python) Execution engine that performs scanning, servo control, image processing, and QR decoding.
- Data Layer Structured storage for debugging outputs, detections, and synchronization.

### Hardware Layer

- USB Camera (IMX258, Waveshare Module) High-resolution sensor used for all image captures. Provides stable frame quality through reduced motion blur during multi-angle scans.
- Two SC15 Serial Servo Motors (Pan–Tilt Unit) Used for orienting the camera across multiple vertical (Bottom–Normal–Top) and horizontal (Left-Normal-Right) viewpoints. Enables angle-sweep scanning for improved QR visibility.
- ESP32-Servo driver expansion board Consists of all the bridges and internal connections required to drive the serial servo motors efficiently. Enables accurate position control of the servo and transmits precise angular feedback back through serial communication.
- On-board RGB LED Controller Two RGB LEDs integrated on the servo driver board act as:
– Status indicators (system health, capture confirmation)
– Motion indicators (servo movement / in-progress scanning)
– Active led safety indicator on movable Z-axis assembly as per standards

### Software Layer

The vision software is divided into an orchestrator and two multiprocessing subsystems:

- visionNode (Orchestrator) Implements a singleton control layer responsible for: – Coordinating multi-angle scan logic
– Controlling LED signaling
– Invoking servo movements through Scanner
– Queue-based communication with the background Processor
- Multiprocessing Architecture The system follows a producer–consumer model:
– Scanner Module (Producer) Captures burst images, selects the sharpest frame, logs metadata, and pushes scan jobs into a multiprocessing queue.
– Processor Worker (Consumer) Continuously consumes queued scan jobs:
∗ Preprocesses and rectifies images
∗ Detects and decodes QR codes
∗ Projects local detections to global coordinates
∗ Updates inventory database
∗ Sends results to remote web API server

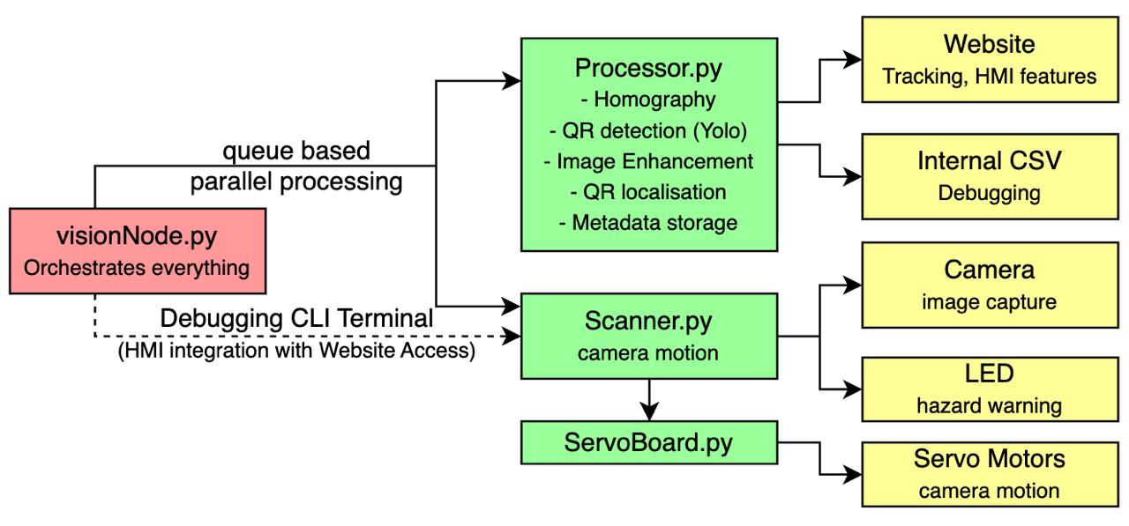
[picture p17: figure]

Figure 5.2: High level architecture of Vision Pipeline

### Data Layer

The system outputs and stores structured data for debugging, analytics, and remote access:

- Raw Image Archive (PNG) Unprocessed captures saved alongside timestamped filenames.
- Metadata CSV Logs Contains pose angle, sharpness score, capture time, and file paths.

- Annotated Debug Images Visual overlays for QR bounding boxes, projections, and decode results.
- Inventory Database (CSV) Maintains the latest decoded QR entries mapped to global coordinates.
- Remote API Server (HTTP POST) Locally hosted web service where the robot pushes processed scan results for user-facing dashboards or warehouse management software.

### 5.2.2 Data Flow Overview

The vision data pipeline comprises three compact layers: input acquisition, multi-stage processing, and structured output generation. This section outlines how raw sensory inputs propagate through the orchestrator, scanner subsystem, background processor, and ultimately into the inventory database and remote server.

Input Layer

- The system receives three sources of data: (a) global pose offsets (x, y) from the SLAM system; (b) scan commands (isTop, isBottom) from the navigation layer; (c) raw frames from the USB camera (IMX258) accessed through the V4L2 backend. Together, these determine the orientation sequence and spatial tagging for each capture.

Processing Layer

- The visionNode acts as the central coordinator: selects orientations, commands the servos, performs LED signalling, triggers frame capture, and enqueues jobs for asynchronous processing.
- Scanner subsystem performs burst acquisition with sharpness-based selection. Each trigger flushes the driver buffer, captures multiple frames via fast grab() and retrieve(), computes Laplacian variance, and stores the sharpest frame with timestamped metadata.
- Processor worker runs in a separate process, loads the saved image, and performs the full pipeline: geometric rectification to camera-frame coordinates; QR localisation using a YOLObased detector; QR enhancement (CLAHE, unsharp masking, thresholding) and decoding via the WeChat engine; centroid-to-global conversion using intrinsics and SLAM offsets; duplicate filtering; inventory file updates; optional annotated-image export; and HTTP transmission of structured scan results to the remote API.

Output Layer

- The pipeline outputs: a consolidated inventory.csv containing session ID, payload, rack/shelf identifiers, and global coordinates; optional annotated frames for debugging; raw captures (subject to deletion policy); and HTTP POST updates consumed by the warehouse management web application. These constitute the interface between onboard perception and higher-level autonomous systems.

### 5.2.3 Design choices and their justifications

- Burst capture + Laplacian selection real robots move. A single-frame capture is brittle; grabbing a short burst and selecting the sharpest image yields substantially higher decode rates for small codes at distance. That’s cheap (a few ms per frame) and reliable.
- Asynchronous worker (multiprocessing) decoding, rectification and networking are CPU/IO heavy. Putting this work into a separate process keeps capture and servo control responsive and avoids blocking the control loop. Using file paths (instead of raw images) avoids heavy interprocess memory transfer.
- Geometric projection before detection QR detectors are typically trained on near-frontoparallel images. Our projection uses physical intrinsics and the servo orientation to synthesize a front normalized view. That improves detector recall and decoder success without collecting extra training data. The camera calibration numbers confirm metric reliability (RMS ≈ 0.45, mean reprojection ≈ 0.06 px), so centroids map into global coordinates with sub-pixel accuracy.
- Explicit intrinsics & distortion handling distortions and principal point offsets bias centroid-to-world conversion. We correct for them up-front so the mapping from pixel to meters is physically meaningful and reproducible across deployments.
- Minimal servo motion planning visionNode tracks the current curr_h/curr_v and sequences moves to avoid unnecessary sweeps, saving time and mechanical wear. This is a simple stateful optimization with big practical upside.
- Simple CSV inventory + Remote POST CSV gives an auditable local store for debugging and offline inspection while the HTTP POST integrates with remote dashboards. This dual output is pragmatic: local traceability plus real-time sync.

Geometric projection and distortion handling are described in detail in the Innovation and Novel Approach section, where the elaborate justification and mathematical basis for these choices are presented.

### 5.2.4 Control Flow: System Initialization Sequence

The scanning pipeline is executed by the visionNode orchestrator, which coordinates servo positioning, image acquisition, background processing, QR decoding, and inventory updates. The complete execution loop is given below.

1. Load Configuration (YAML) All camera, servo, processor, and session parameters are loaded from config.yaml. This includes:
| • Camera parameters (resolution, FPS, codec) • Servo configuration (port, baud rate, angular mapping) • Processor thresholds (QR confidence, NMS, padding) • Session information (round ID, server URL)
2. Initialize visionNode Singleton Creates log directories, initializes the scanner, sets home servo position, and spawns the background processor.
3. Scanner Subsystem Initialization
| • Connects to camera using V4L2 (video four linux v2) backend

- Configures image properties (width/height/FPS) and FourCC codec
- Performs warm-up reads
- Initializes servo hardware (servoBoard)
4. Launch Processor Worker (On multiprocessing queue) The worker process continuously waits for incoming tasks on a shared queue.
- Queue capacity = 50 tasks
- Each task contains: image path, SLAM offsets, camera orientation
5. System Ready Scanner is active, servos are at neutral orientation, and the processor is ready to accept images.

### 5.2.5 Scanner Subsystem: Optimized Frame Acquisition

The Scanner module is responsible for all low-level image acquisition tasks. Its design ensures that each scan request produces the sharpest possible frame, even under vibration, robot motion, or varying lighting conditions. Instead of relying on a single capture, the scanner performs a structured burst-capture and post-selection workflow. This significantly improves the quality of downstream QR detection and geometric rectification.

Burst Capture and Sharpness-Based Selection

The full internal workflow is as follows:

1. Burst Capture (10 frames)
| • Flush camera buffer by discarding the first 3 frames (eliminates stale frames from the driver queue) • Use grab() for fast frame acquisition (no immediate decoding, hence minimal latency) • Use retrieve() to decode only the frames that were grabbed
2. Sharpness Analysis For each retrieved frame:
| • Convert the frame to grayscale • Apply the Laplacian operator to estimate edge strength • Compute the variance of the Laplacian response (a higher value indicates a sharper image) • Track and select the frame with the highest sharpness score
3. Persisting the Best Frame Once the sharpest frame is identified:
| • The image is saved with a timestamp-based name: capture_YYYY-MM-DD_HH-MM- SS.png • Files are stored under the configured raw-capture directory (e.g. /data/raw_captures/ ) • A metadata entry containing timestamp, filename, resolution, and sharpness score is appended to a CSV log

This subsystem ensures that every capture request produces a clean, stable, and high-quality input image. These saved images are then asynchronously consumed by the processor_worker, which performs geometric rectification, QR detection, decoding, and global coordinate mapping.

### 5.2.6 QR Detection Pipeline

QR detection in the system follows a clear multi stage pipeline built for warehouse conditions such as changing light, narrow aisles and a moving platform. Each step cleans the image and refines the candidates so that the final detections stay reliable.
The entire pipeline has two major sections

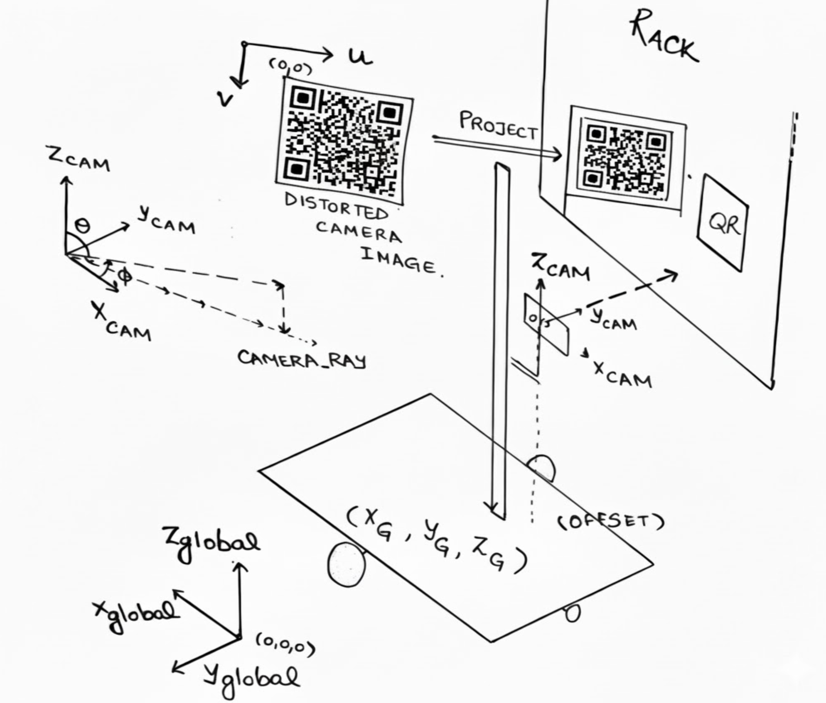
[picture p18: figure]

Figure 5.3: We use the above three coordinate frames to establish a 3D projection of image to a plane parallel to the rack (Geometric Rectification)

A) Geometric Rectification
1. Convert orientation (0,1,2) into camera pitch/yaw angles using the orientation map defined in the processor module

Down → (180◦

, 90◦

), Front → (90◦

, 90◦

), Up → (0◦

, 90◦
)
2. Compute rotation matrix R using camera model:

R = [xcam, ycam, zcam]

3. For each pixel (u, v), obtain the undistorted ray direction:

⃗rworld = R · K⁻¹
(u, v)
4. Intersect this ray with the warehouse wall plane at distance d to obtain real-world surface coordinates:
t =

d
ry
, | xcam = t · rx, | ycam = t · rz
5. Construct a rectified top-down camera-frame image where pixel distances correspond to real physical distances (pixels-per-meter scale).

This make sure that QR codes have the ideal geometric properties on which algorithms/models are built. Low-light conditions necessitate this additional preprocessing since it made significant difference to our pipeline.

B) Detection of QR Candidates

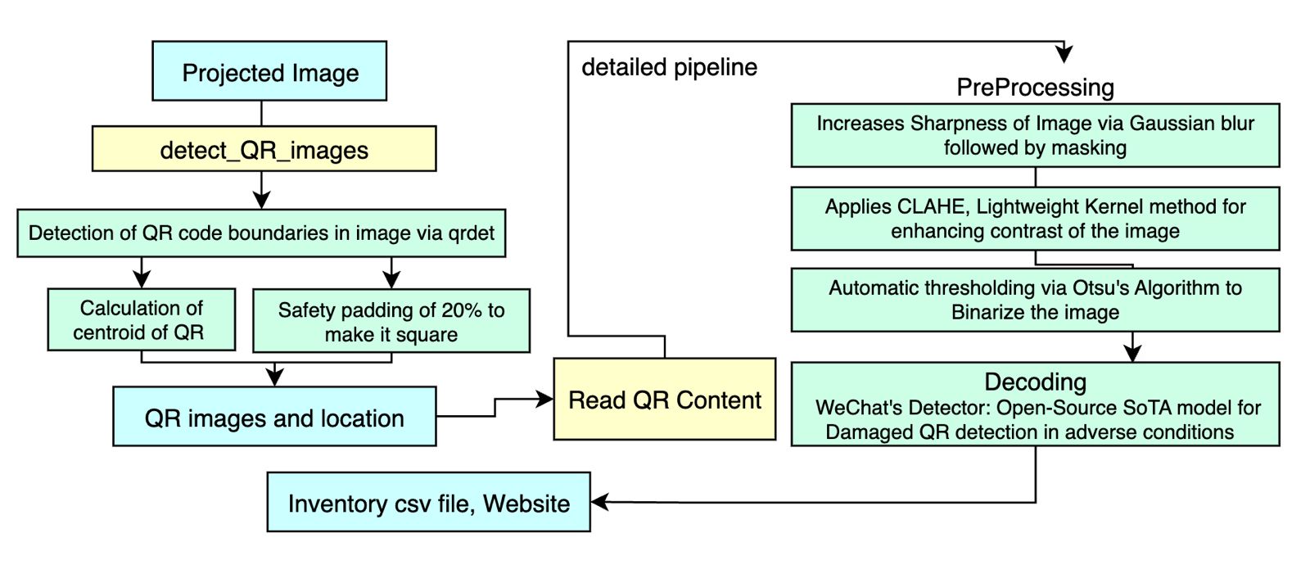
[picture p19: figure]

Figure 5.4: QR code processing pipeline from projected image to inventory records.

The rectified frame is passed to the YOLO based QRDetector model.

1. Detector outputs bounding boxes (x1, y1, x2, y2) with confidence filtering and NMS (configurable).
2. Each bounding box is:
- Clamped to image boundaries
- Converted to centroid (uc, vc) for coordinate mapping
- Padded based on box size (ratio defined in YAML)
- Cropped from the projection image
3. Cropped regions are converted to a square shape using _make_square_canvas() to preserve QR finder pattern ratios.

This produces high-quality QR tiles for decoding.

C) Enhancement Pipeline

Each cropped QR region is normalized via the following transformation stack:

1. Resize to a fixed 400 × 400 resolution (Lanczos)
2. Apply CLAHE for contrast enhancement
3. Apply Unsharp Mask to sharpen edges
4. Apply binary thresholding for readability

This step significantly improves decoding success in low-light warehouse environments.

D) Decoding (WeChat QR Engine)

Decoding uses OpenCV’s WeChat QR inference engine:

payload = WeChatQRCode.detectAndDecode(Ibinary)

The detector is lazy-loaded to reduce memory overhead and avoid startup delays. Empty or unreadable QRs return a null string.

E) Coordinate Mapping to Global Frame

For each decoded QR:

xcam =

uc
ppm
+ xcam_origin, | ycam = ycam_origin −

vc
ppm

Global coordinates incorporate SLAM offsets:

xglobal = xcam + x0, | yglobal = ycam + y0

This allows each QR code to be placed accurately on the warehouse map.

### 5.2.7 Processing and Data Logging Pipeline

Once QR data and coordinates are available, the processor executes a complete inventory management workflow:

1. Parse Payload Format: R03_S4_ITM240 Extracted as: rack, shelf, item.
2. Duplicate Checking Each entry is checked against:
- Previously scanned items from the same session
- Distance-based duplicate thresholds on global coordinates of centroid(X/Y meters)
3. Inventory Update Depending on the condition:
- New item → create new row
- Same item, same location → ignore
- Same item, new location → create new row
4. Optional Annotated Image Saving Boxes are drawn on the full frame and written to the annotated output directory for debugging and visualization purposes.
5. Remote API POST Each valid entry is sent to the web server:[/api/update]

This completes the closed-loop scanning and inventory registration cycle.

## 5.3 HMI Design

The human machine interface provides a simple web based view of the rover and its interaction with the warehouse. It is designed to run on the Host PC itself or on a nearby support machine that can reach the robot over the network.

### 5.3.1 Front-End Structure

Figure 5.5: Real-time warehouse inventory dashboard showing rack status, search, and event logs

The front end resides in a template directory and consists mainly of two pages:

- login.html: Presents a username and password form. On submission the credentials are sent as a POST request to the Flask back end. Valid credentials create a session and redirect the user to the dashboard. Invalid credentials keep the user on the login page with a short error message.
- dashboard.html: Acts as the main monitoring screen. It displays a vertically scrollable list of rack cards, where each card contains the rack identifier, shelf identifier and Item Code label. Additional widgets show the current run identifier and timestamps of the last updates. The layout is optimised for continuous viewing on a laptop or a control tablet.¹

The dashboard obtains its data through JavaScript calls to the Flask API. It polls the back end at a fixed rate to fetch the latest JSON snapshots. Small updates, such as a single rack changing from unknown to full, only update the corresponding card on screen.

### 5.3.2 Back-End Architecture

The HMI back end is a Flask application located in the backend folder of the codebase. The main elements are:

- app.py: Entry point that creates the Flask app, configures session handling and registers all routes. It also contains helper functions to read and write CSV files, and to package the data as JSON responses for the dashboard.
- data/ directory: Contains rover_data.csv, racks.csv and inventory.csv. These files store telemetry, rack structure and inventory events. The back end appends new rows for each scan and reads the full set when serving dashboard requests.
- Utilities: Small route files and helper scripts such as restart_run.py provide endpoints for

1Front end behaviour follows the website documentation.

restarting a run or performing local tests.²

The overall data path is:

1. Navigation and perception nodes publish scan results and inventory updates.
2. Logging utilities write these events into the CSV files in the data/ folder.
3. The Flask app parses the CSV files on request and returns JSON objects that group entries by rack and shelf.
4. The dashboard receives the JSON payload and updates the rack cards on screen.

This design keeps the HMI independent of ROS message formats while still reflecting the live state of the robot.

(Space for a sequence diagram that shows ROS topics, CSV logging, Flask routes and dashboard updates.)

### 5.3.3 Role in the Overall System

The HMI sits at the outer edge of the software stack. It does not send direct motion commands to the robot. Instead, it reports what the robot has already done and what it has observed. Operators use it to:

- confirm that scans have been completed for a set of racks,
- check that the battery is within the safe range before starting long runs, and
- export inventory CSV files for further analysis or import into a warehouse management system.

By keeping the HMI loosely coupled in this way, the navigation and scanning pipelines can evolve without forcing large changes in the user facing components.

5.4 | Communication Protocols
5.4.1 | Software Stack Overview

The mapping and navigation stack is built on ROS 2 with the Nav2 framework acting as the main navigation layer. On top of the base ROS 2 middleware, we use the following core packages:

- slam_toolbox for online SLAM and map management.
- robot_localization for state estimation using an extended Kalman filter.
- nav2_bringup and the broader Nav2 stack for path planning, control, and recovery behaviors.

The Jetson Orin Nano runs these nodes, while Arduino-based controllers provide low-level sensor and odometry topics over serial bridges. The TF tree follows the standard ROS 2 convention and includes map, odom and base_link frames, with slam_toolbox maintaining the map→odom transform and robot_localization maintaining the odom→base_link transform.

2Folder layout based on the website documentation.

### 5.4.2 Module-wise Architecture

Perception Pipeline

For mapping and navigation, we use three primary sensing modalities:

- a RP 2D LiDAR publishing range scans on /scan topic,
- an IMU(BNO055) publishing linear acceleration and angular velocity on /imu topic
- wheel and lift motor encoders combined into odometry messages on /odom topic.

The robot_localization package fuses /imu and /odom using an extended Kalman filter configured for a differential-drive platform. This filter outputs a continuous estimate of the robot pose and velocity in the odom frame, which is then consumed by both slam_toolbox and the Nav2 local planner.

LiDAR data from /scan is used in two ways:

- by slam_toolbox to align successive scans and refine the map and map→odom transform
- by the Nav2 costmap layers to build obstacle and inflation maps for collision avoidance.

The QR-based vision pipeline described in the previous chapter runs in parallel and is not part of the navigation loop. Its role is to identify rack locations once the mapping and navigation stack has brought the robot to the desired scan poses.

# Chapter 6

# Integration & Control
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

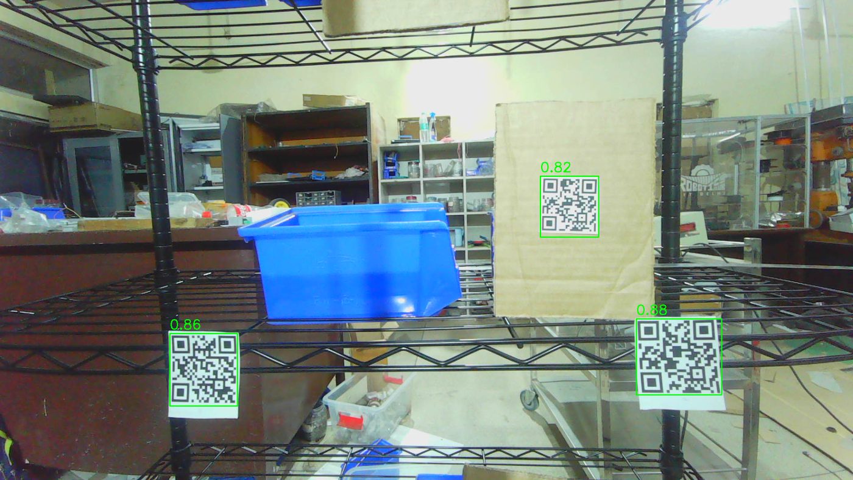
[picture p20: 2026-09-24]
docs/assets/hero-qr-scan.jpg

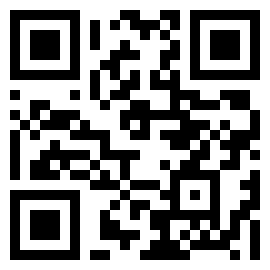
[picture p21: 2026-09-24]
docs/assets/qr-sample.png

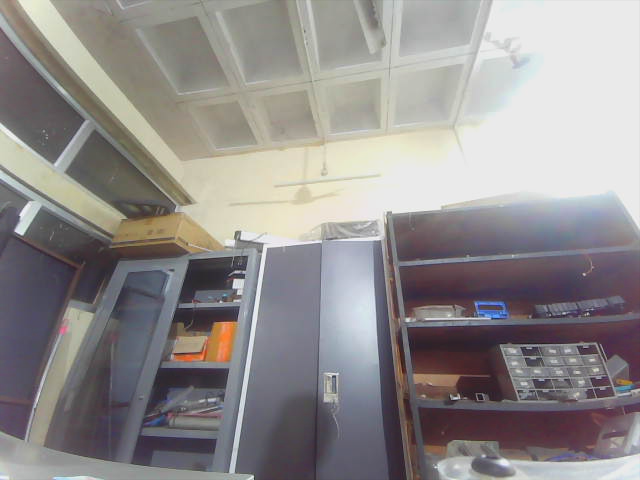
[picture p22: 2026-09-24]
vision/website/captures/burst_2025-12-03_06-02-02.png

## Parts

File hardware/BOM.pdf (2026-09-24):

Part_ID | Part_Name | Manufacturer | Item Label | Qty. | Price per piece | Total Price | Estimate d Time of Delivery | Datasheet/ Specifications/ Supporting docs
SKU: 3405 | Cytron MDD10A | Macfos LTD | Cytron MDD10A Dual Channel Enhanced 10Amp DC Motor Driver 30A Peak | 2 | ₹1,992.00 | ₹3,984.00 | 2-3 Days | Datasheet (https://robu.in/wp-content/uploads/2015/01/MDD10A-Users-Manual-Google-Docs.pdf)
SKU: 815794 | Buck Converters | Macfos LTD | 200W 20A DC-DC Buck Converter Step Down Module Constant Current LED Driver Module | 2 | ₹369.00 | ₹738.00 | 2-3 Days | Specifications (https://robu.in/product/200w-20a-dc-dc-buck-converter-step-down-module-constant-current-led-driver-module/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)
SKU: 9175 | Wheel hub (10mm) | Macfos LTD | EasyMech ID-10mm Motor Coupling Hub | 2 | ₹531.00 | ₹1,062.00 | 2-3 Days | Schematic (https://robu.in/wp-content/uploads/2016/02/4.png)
SKU: R110597 | Shaft coupling | Macfos LTD | EasyMech 8×10 Aluminium Rigid coupling | 2 | ₹336.00 | ₹672.00 | 2-3 Days | Datasheet (https://robu.in/wp-content/uploads/2024/03/rigid-coupling-2.pdf)
SKU: 559684 | 3D Printer Filament | Macfos LTD | eSUN PLA+ 1.75mm 3D Printing Filament 1kg | 1 | ₹1,270.00 | ₹1,270.00 | 2-3 Days | User Manual (https://robu.in/wp-content/uploads/2019/03/eSUN-Product-Catalogue-latest.pdf)
SKU: R255021 | Emergency button | Macfos LTD | ONPOW6319-01TS/J/G/24V/PA+S10-1950 | 2 | ₹635.00 | ₹1,270.00 | 1-2 Days | Datasheet (https://robu.in/wp-content/uploads/2025/10/ONPOW6319-TS-J-PAled.pdf)
SKU: 1320700 | Emergency LED | Macfos LTD | 12-18V 5MM Water Clear RGB Slow Flash LED Metal Indicator Light with 20CM | 1 | ₹134.00 | ₹134.00 | 1-2 Days | Specifications (https://robu.in/product/12-18v-5mm-water-clear-rgb-slow-flash-led-metal-indicator-light-with-20cm-pack-of-5/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)
SKU: R196225 | Emergency Buzzer | Macfos LTD | SmartElex Active Buzzer Module | 1 | ₹40.00 | ₹40.00 | 2-3 Days | Specifications (https://robu.in/product/smartelex-active-buzzer-module/#tab-specification)
- | BNO0055 | Adafruit | BNO055 9-DOF Absolute Orientation Sensor | 1 | ₹1,349.99 | ₹1,349.99 | 2-3 Days | Datasheet (https://github.com/thinkrobotics/DATASHEET/blob/master/ELECTRONIC_COMPONENTS/ELC1016/Datasheet%20for%20ELC1016.pdf)
- | Camera | Waveshare | IMX258 13MP OIS USB Camera with Optical Image Stabilization | 1 | ₹9,499.00 | ₹9,499.00 | 8-10 Days | Specifications (https://thinkrobotics.com/products/imx258-13mp-usb-camera-with-ois-online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)
- | SSD 500GB | Zebronics | WD Green SN350 / Zebronics MN26 NVMe SSD | 1 | ₹5,199.99 | ₹5,199.99 | 2-3 Days | Specifications (https://thinkrobotics.com/products/wd-green-sn350-nvme-ssd?variant=43952799842621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)
SKU: 28496 | 6x8 coupler | Balaji Engineering Works | Precision Flexible Shaft Couplers | 2 | ₹149.00 | ₹298.00 | 2-3 Days | Specifications (https://thinkrobotics.com/products/set-screw-precision-flexible-shaft-couplers?variant=39635203850326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)
- | 100Ah Battery | LRSA Technology | 12V 100ah LifePo4 battery Rechargeable Battery 12v 100000mah battery- LRSA TECHNOLOGY PVT. LTD | 1 | ₹16,999.00 | ₹16,999.00 | 2-3 Days | Description (https://lrsa.in/product/12v-100ah-lithium-ion-rechargeable-battery-12v-100000mah-battery-li-ion-lrsa-technology-pvt-ltd/)
SKU R199100 | Jetson Orin Nano | Macfos LTD | NVIDIA Jetson Orin Nano Super Developer Kit | 1 | ₹ 33,999.00 | ₹ 33,999.00 | 8-10 Days | Specification (https://docs.rs-online.com/4051/A700000009607470.pdf)
| Mega Arduino 2560 | | | 3 | ₹149.00 | ₹149.00 | 2-3 Days
SKU 1507765 | LiDAR | Macfos LTD | RPLiDAR S2E 360 Degree Laser Range Scanner – 30M Range, 2D point cloud map, 80000 lux light resistance, IP65, high safety for human eye Model: S2M1-R2E | 1 | ₹29,999.00 | ₹29,999.00 | 8-10 Days | Datasheet (https://robu.in/wp-content/uploads/2023/03/SLAMTEC_rplidar_datasheet_S2E_v1.8_en.pdf)
SKU: 1219081 | Servo Motor SC15 | Macfos LTD | Waveshare SC15 17kg Large Torque Programmable Serial Bus Servo | 2 | ₹1,669.00 | ₹3,338.00 | 2-3 Days | Specification (https://robu.in/product/waveshare-sc15-17kg-large-torque-programmable-serial-bus-servo/)
SKU: R254743 | ESP Controller | Espressif Systems | ESP32-S3-MOD-8M Module | 1 | ₹413.00 | ₹413.00 | 2-3 Days | Datasheet (https://robu.in/wp-content/uploads/2025/07/R254743-ESP32-S3-MOD-8M-Datasheet.pdf)
- | Battery 12.8V | LRSA Technology | 100Ah Customized | 1 | ₹17,000.00 | ₹17,000.00 | 1 week | Customized
SKU: 24494 | IG42 Motors | Macfos LTD | Planetary DC Geared Motor 1400 RPM 22N-CM 12V IG42E-04K | 2 | ₹8,172.00 | ₹16,344.00 | 2-3 Days | Specification (https://robu.in/product/planetary-dc-geared-motor-1400-rpm-22-n-cm-12v-42mm-ig42e-04k/)
SKU: 649521 | IG45 Motor | Macfos LTD | Planetary DC Geared Motor 438 RPM 78N-CM 24V IG45-14K | 1 | ₹4,628.00 | ₹4,628.00 | 2-3 Days | Specification (https://robu.in/product/planetary-dc-geared-motor-438-rpm-78n-cm-24v-ig45-14k/#tab-specification)
SKU: 959868 | Wheels (100mm dia) | Macfos LTD | 100mm Wheels with Plastic Rim – 2 Pcs | 2 | ₹1,250.00 | ₹2,500.00 | 2-3 Days | Specification (https://robu.in/product/100mm-wheels-with-alloy-rim-2-pcs/#tab-specification)
SKU: 501343 | Chrome Plated rod (10mm D, 500mm) | Macfos LTD | 500 MM long Chrome Plated Smooth Rod Diameter 10 MM | 1 | ₹389.00 | ₹389.00 | 2-3 Days | Specification (https://robu.in/product/500-mm-long-chrome-plated-smooth-rod-diameter-10-mm/#tab-specification)
SKU: 501201 | Chrome Plated rod (8mm D, 400mm) | Macfos LTD | 400 MM long Chrome Plated Smooth Rod Diameter 8 MM | 1 | ₹195.00 | ₹195.00 | 2-3 Days | Specification (https://robu.in/product/400-mm-long-chrome-plated-smooth-rod-diameter-8-mm/#tab-specification)
| Miscellanous(Fasteners,Standoffs, Bolts,Washers etc) | | | 1 | ₹5,000.00 | ₹5,000.00 | 2-3 Days

Part_ID | Part_Name | Manufacturer | Item Label | Qty. | Price per piece | Total Price | Estimate d Time of Delivery | Datasheet/ Specifications/ Supporting docs
SKU: 52350 | KP08 | Macfos LTD | KP08 8mm Bore Inner Ball Mounted Pillow Block Insert Bearing | 8 | ₹69.00 | ₹552.00 | 2-3 Days | Specification (https://robu.in/product/8mm-bore-inner-ball-mounted-pillow-block-insert-bearing-kp08/)
SKU: 52357 | KP000 | Macfos LTD | KP000 10mm Bore Inner Ball Mounted Pillow Block Insert Bearing | 2 | ₹98.00 | ₹196.00 | 2-3 Days | Specification (https://robu.in/product/10mm-bore-inner-ball-mounted-pillow-block-insert-bearing-kp000/)
| Total | | | | | ₹123,218.98

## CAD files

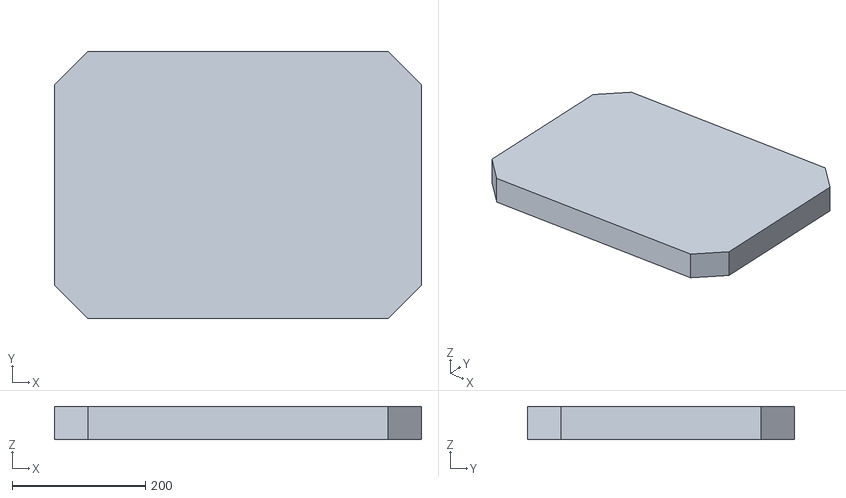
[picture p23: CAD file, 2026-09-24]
code/src/src/bot_description/urdf/meshes/base_link.stl
550.0 x 400.0 x 50.0

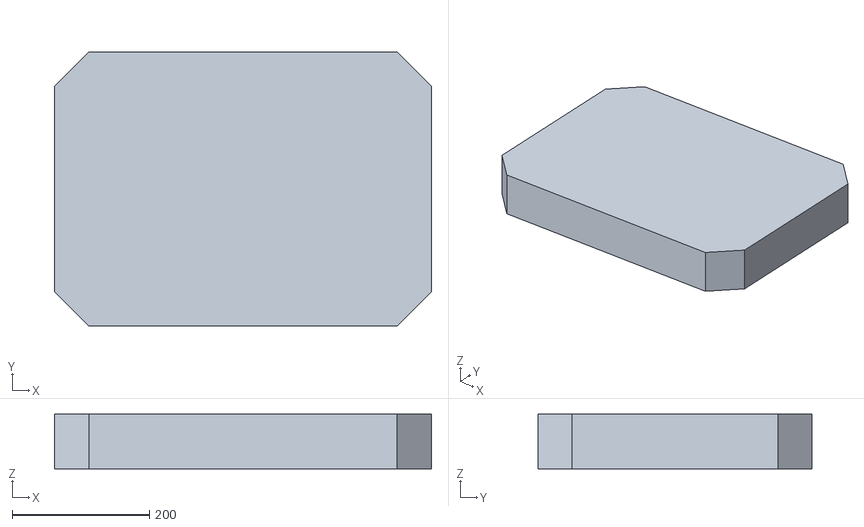
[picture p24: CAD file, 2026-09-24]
code/src/src/bot_description/urdf/meshes/upper_box.stl
550.0 x 400.0 x 80.0

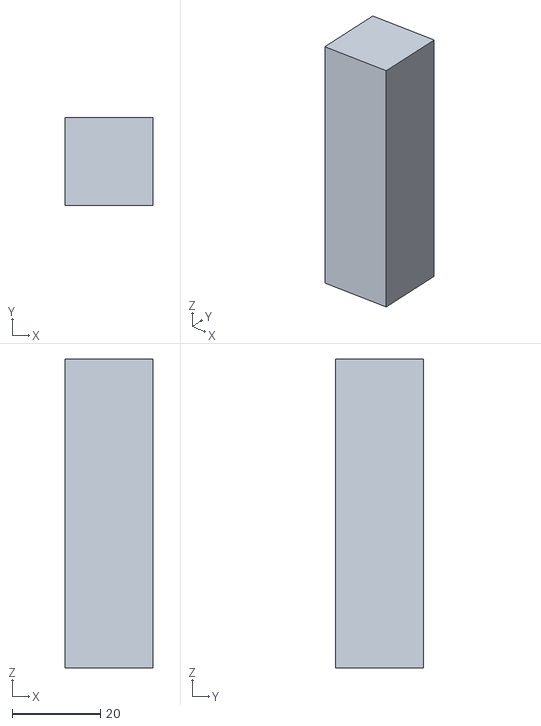
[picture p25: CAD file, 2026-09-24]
code/src/src/bot_description/urdf/meshes/pillars.stl
20.0 x 20.0 x 70.0

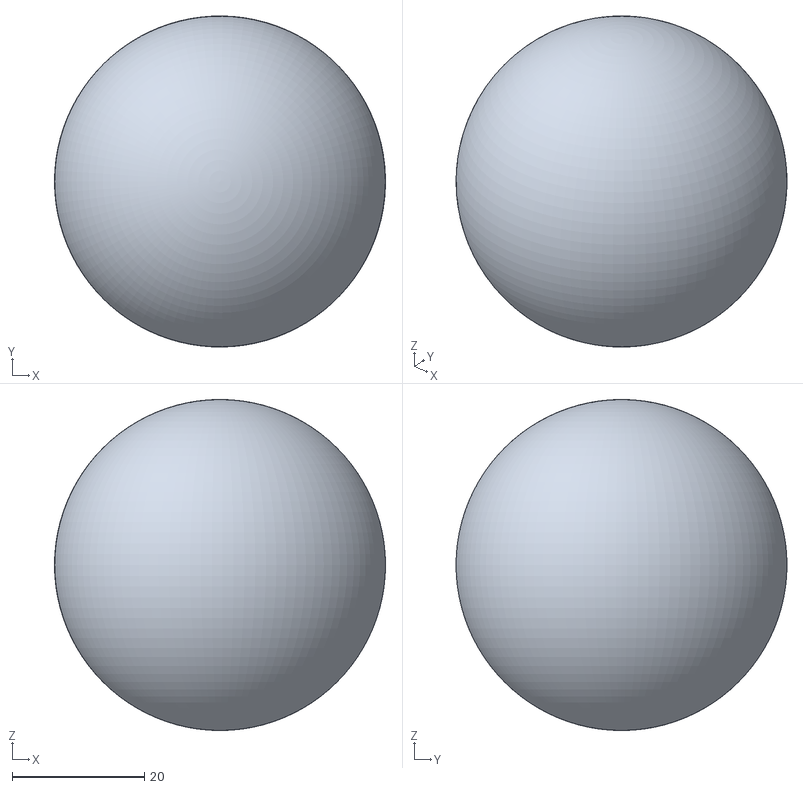
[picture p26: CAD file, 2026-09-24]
code/src/src/bot_description/urdf/meshes/sphere.stl
50.0 x 50.0 x 50.0

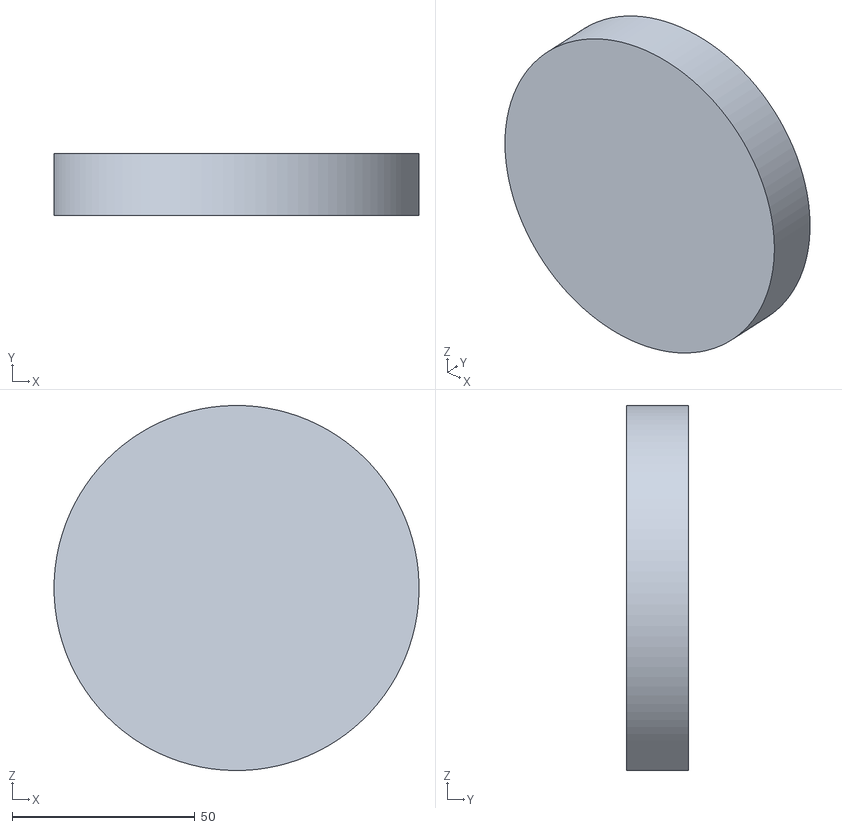
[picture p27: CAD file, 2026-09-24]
code/src/src/bot_description/urdf/meshes/wheel.stl
100.0 x 17.0 x 100.0

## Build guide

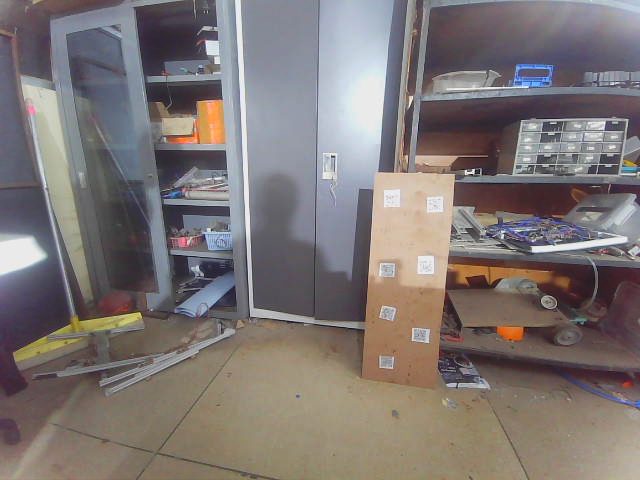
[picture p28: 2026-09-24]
docs/assets/lab-qr-setup.jpg

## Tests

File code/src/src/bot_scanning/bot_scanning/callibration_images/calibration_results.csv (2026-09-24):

Image Index | Image Name | Reprojection Error (px)
0 | captureZKP/img9.jpg | 0.031845112115270545
1 | captureZKP/img8.jpg | 0.06037684896241107
2 | captureZKP/img5.jpg | 0.0529751484165985
3 | captureZKP/img4.jpg | 0.04857614329266002
4 | captureZKP/img6.jpg | 0.13109599578291753
5 | captureZKP/img7.jpg | 0.05378419543485801
6 | captureZKP/img3.jpg | 0.03830639018101941
7 | captureZKP/img2.jpg | 0.0352690785215363
8 | captureZKP/img1.jpg | 0.05471253853550509
9 | captureZKP/img16.jpg | 0.09225484632039328
10 | captureZKP/img14.jpg | 0.07190013155327502
11 | captureZKP/img15.jpg | 0.07249214604325038
12 | captureZKP/img11.jpg | 0.05376890384540989
13 | captureZKP/img10.jpg | 0.033166210087069034
14 | captureZKP/img12.jpg | 0.08685287425693057
15 | captureZKP/img13.jpg | 0.04419221713420921
--- GLOBAL PARAMETERS ---
RMS (Calibration Success Flag) | 0.4517706674904639
Mean Reprojection Error | 0.06009804878020711
Camera Matrix (Intrinsics)
265.8567729497821 | 0.0 | 320.3958255739504
0.0 | 267.2568937166672 | 234.28725155362122
0.0 | 0.0 | 1.0
Distortion Coefficients
-0.08822294208758422 | 0.17788338245027485 | 3.428890414162533e-05 | -0.0007590912513493434 | -0.09579918378535092

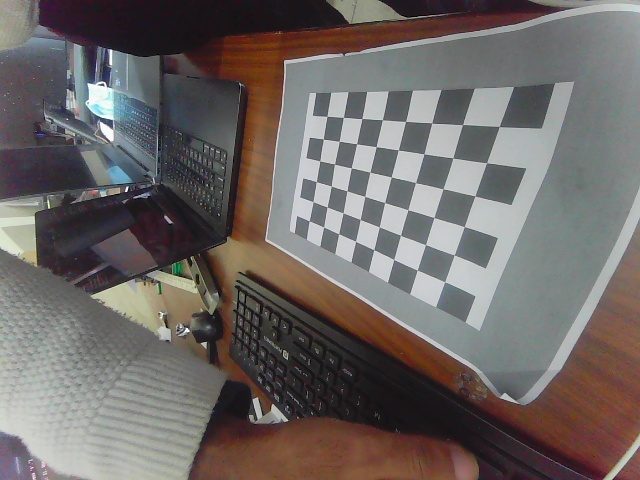
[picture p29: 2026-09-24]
docs/assets/camera-calibration.jpg

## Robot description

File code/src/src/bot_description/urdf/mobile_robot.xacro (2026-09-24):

<?xml version="1.0"?>
<robot xmlns:xacro="http://www.ros.org/wiki/xacro">
  <xacro:property name="base_length" value="0.55" />
  <xacro:property name="base_width" value="0.4" />
  <xacro:property name="base_height" value="0.06" />
  <xacro:property name="wheel_radius" value="0.05" />
  <xacro:property name="wheel_length" value="0.02" />
  <xacro:macro name="wheel_link" params="prefix">
    <link name="${prefix}_wheel_link">
       <visual>
        <geometry>
          <cylinder radius="${wheel_radius}" length="${wheel_length}" />
        </geometry>
        <origin xyz="0 0 0" rpy="${pi / 2.0} 0 0" /><material name="gray" />
      </visual>
      <collision>
        <geometry>
          <sphere radius="${wheel_radius}"/>
        </geometry>
        <origin xyz="0 0 0" rpy="0 0 0" /><material name="gray" />
      </collision>
      <xacro:cylinder_inertia m="1.0" r="${wheel_radius}" l="${wheel_length}" o_xyz="0 0 0" o_rpy="${pi / 2.0} 0 0" />
    </link>
  </xacro:macro>
  <link name="base_link">
    <visual>
      <geometry>
        <box size="${base_length} ${base_width} ${base_height}" />
      </geometry>
      <origin xyz="0 0 ${base_height / 2.0}" rpy="0 0 0" />
      <material name="green" />
    </visual>
    <collision>
      <geometry>
        <box size="${base_length} ${base_width} ${base_height}" />
      </geometry>
      <origin xyz="0 0 ${base_height / 2.0}" rpy="0 0 0" />
    </collision>
    <xacro:box_inertia m="5.0" x="${base_length}" y="${base_width}" z="${base_height}" o_xyz="0 0 ${base_height / 2.0}" o_rpy="0 0 0" /> 
  </link>
  <xacro:wheel_link prefix="right" />
  <!-- <link name="right_wheel_link">
    <visual>
      <geometry>
        <cylinder radius="${wheel_radius}" length="${wheel_length}" />
      </geometry>
      <origin xyz="0 0 0" rpy="${pi / 2.0} 0 0" />
      <material name="gray" />
    </visual>
  </link> -->
  <joint name="base_right_wheel_joint" type="continuous">
    <parent link="base_link" />
    <child link="right_wheel_link" />
    <origin xyz="0 ${-(base_width + wheel_length) / 2.0} 0" rpy="0 0 0" />
    <axis xyz="0 1 0" rpy="0 0 0"/>
  </joint>
  <xacro:wheel_link prefix="left" />
  <!-- <link name="left_wheel_link">
    <visual>
      <geometry>
        <cylinder radius="${wheel_radius}" length="${wheel_length}" />
      </geometry>
      <origin xyz="0 0 0" rpy="${pi / 2.0} 0 0" />
      <material name="gray" />
    </visual>
  </link> -->
  <joint name="base_left_wheel_joint" type="continuous">
    <parent link="base_link" />
    <child link="left_wheel_link" />
    <origin xyz="0 ${(base_width + wheel_length) / 2.0} 0.0" rpy="0 0 0" />
    <axis xyz="0 -1 0" rpy="0 0 0"/>
  </joint>
  <link name="caster_wheel_link_front">
    <visual>
      <geometry>
        <sphere radius="${wheel_radius / 2.0}" />
      </geometry>
      <origin xyz="0 0 0" rpy="0 0 0" />
      <material name="gray" />
    </visual>
    <collision>
      <geometry>
        <sphere radius="${wheel_radius / 2.0}" />
      </geometry>
      <origin xyz="0 0 0" rpy="0 0 0" />
    </collision>
    <xacro:sphere_inertia m="0.5" r="${wheel_radius / 2.0}" o_xyz="0 0 0" o_rpy="0 0 0" />
  </link>
  <joint name="base_caster_wheel_joint" type="fixed">
    <parent link="base_link" />
    <child link="caster_wheel_link_front" />
    <origin xyz="${base_length / 3.0} 0 ${-wheel_radius / 2.0}" rpy="0 0 0" />
  </joint>

  <link name="caster_wheel_link_back">
    <visual>
      <geometry>
        <sphere radius="${wheel_radius / 2.0}" />
      </geometry>
      <origin xyz="0 0 0" rpy="0 0 0" />
      <material name="gray" />
    </visual>
    <collision>
      <geometry>
        <sphere radius="${wheel_radius / 2.0}" />
      </geometry>
      <origin xyz="0 0 0" rpy="0 0 0" />
    </collision>
    <xacro:sphere_inertia m="0.5" r="${wheel_radius / 2.0}" o_xyz="0 0 0" o_rpy="0 0 0" />
  </link>
  <joint name="base_caster_wheel_joint2" type="fixed">
    <parent link="base_link" />
    <child link="caster_wheel_link_back" />
    <origin xyz="${-base_length / 3.0} 0 ${-wheel_radius / 2.0}" rpy="0 0 0" />
  </joint>

  <link name="base_footprint">
    <!-- <inertial>
      <mass value="0.0001"/> 
      <origin xyz="0 0 0" rpy="0 0 0"/>
      <inertia ixx="1e-6" ixy="0" ixz="0" iyy="1e-6" iyz="0" izz="1e-6"/>
    </inertial> -->
  </link>

  <joint name="base_joint" type="fixed">
    <parent link="base_link" />
    <child link="base_footprint" />
    <origin xyz="0 0 0" rpy="0 0 0" />
  </joint>

  
  
</robot>

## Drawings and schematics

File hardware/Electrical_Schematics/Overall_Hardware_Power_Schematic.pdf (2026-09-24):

# LITHIUM BATTERY 12V 100Ah,50Amp

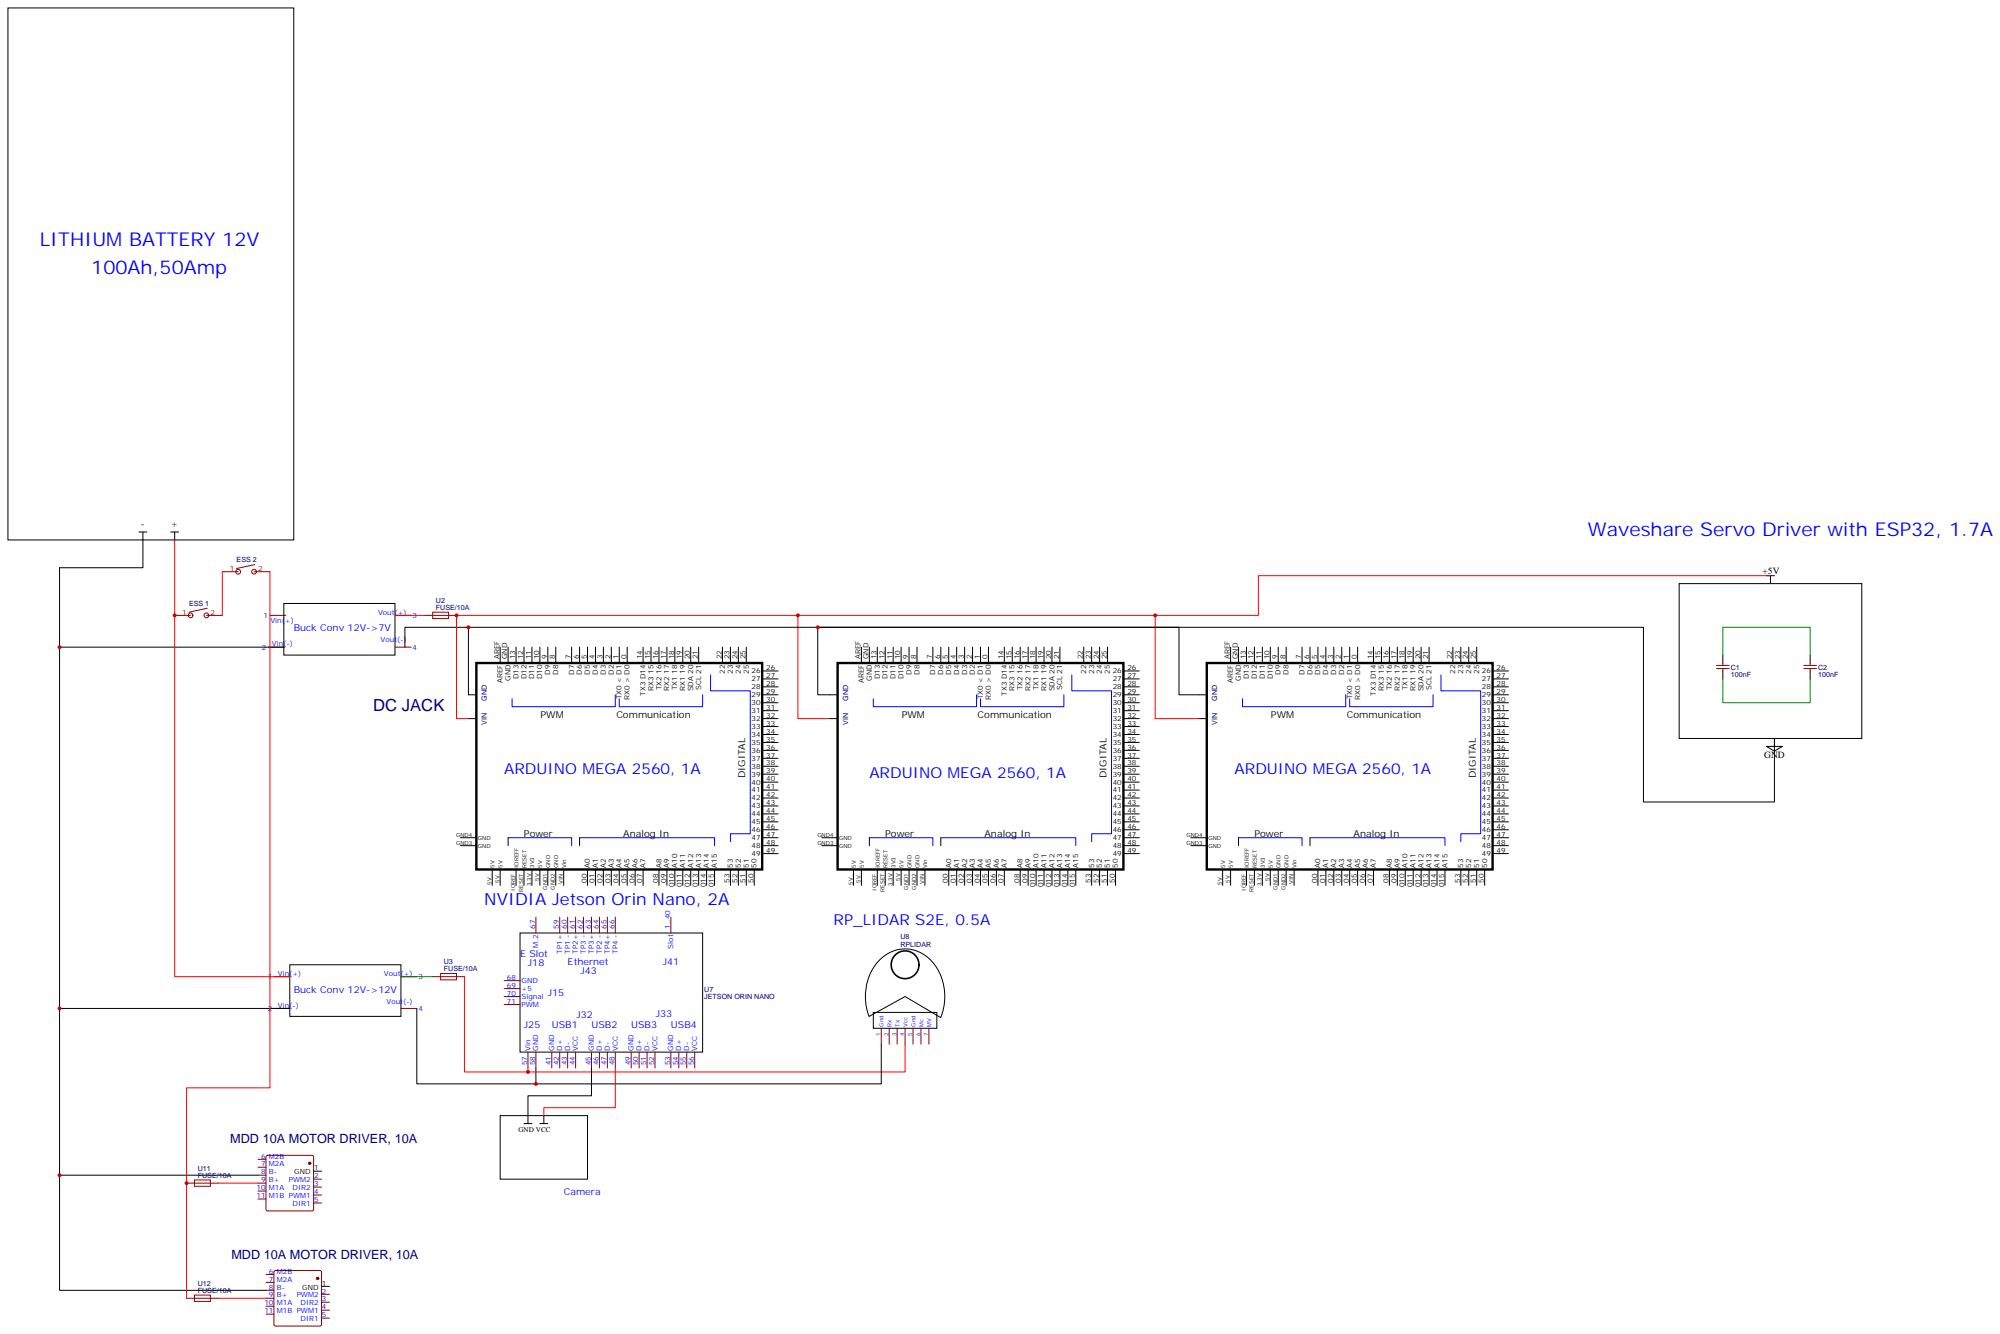
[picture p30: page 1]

Waveshare Servo Driver with ESP32, 1.7A

NVIDIA Jetson Orin Nano, 2A

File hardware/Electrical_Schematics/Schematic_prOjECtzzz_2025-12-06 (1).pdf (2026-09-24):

# LITHIUM BATTERY 12V 100Ah,50Amp

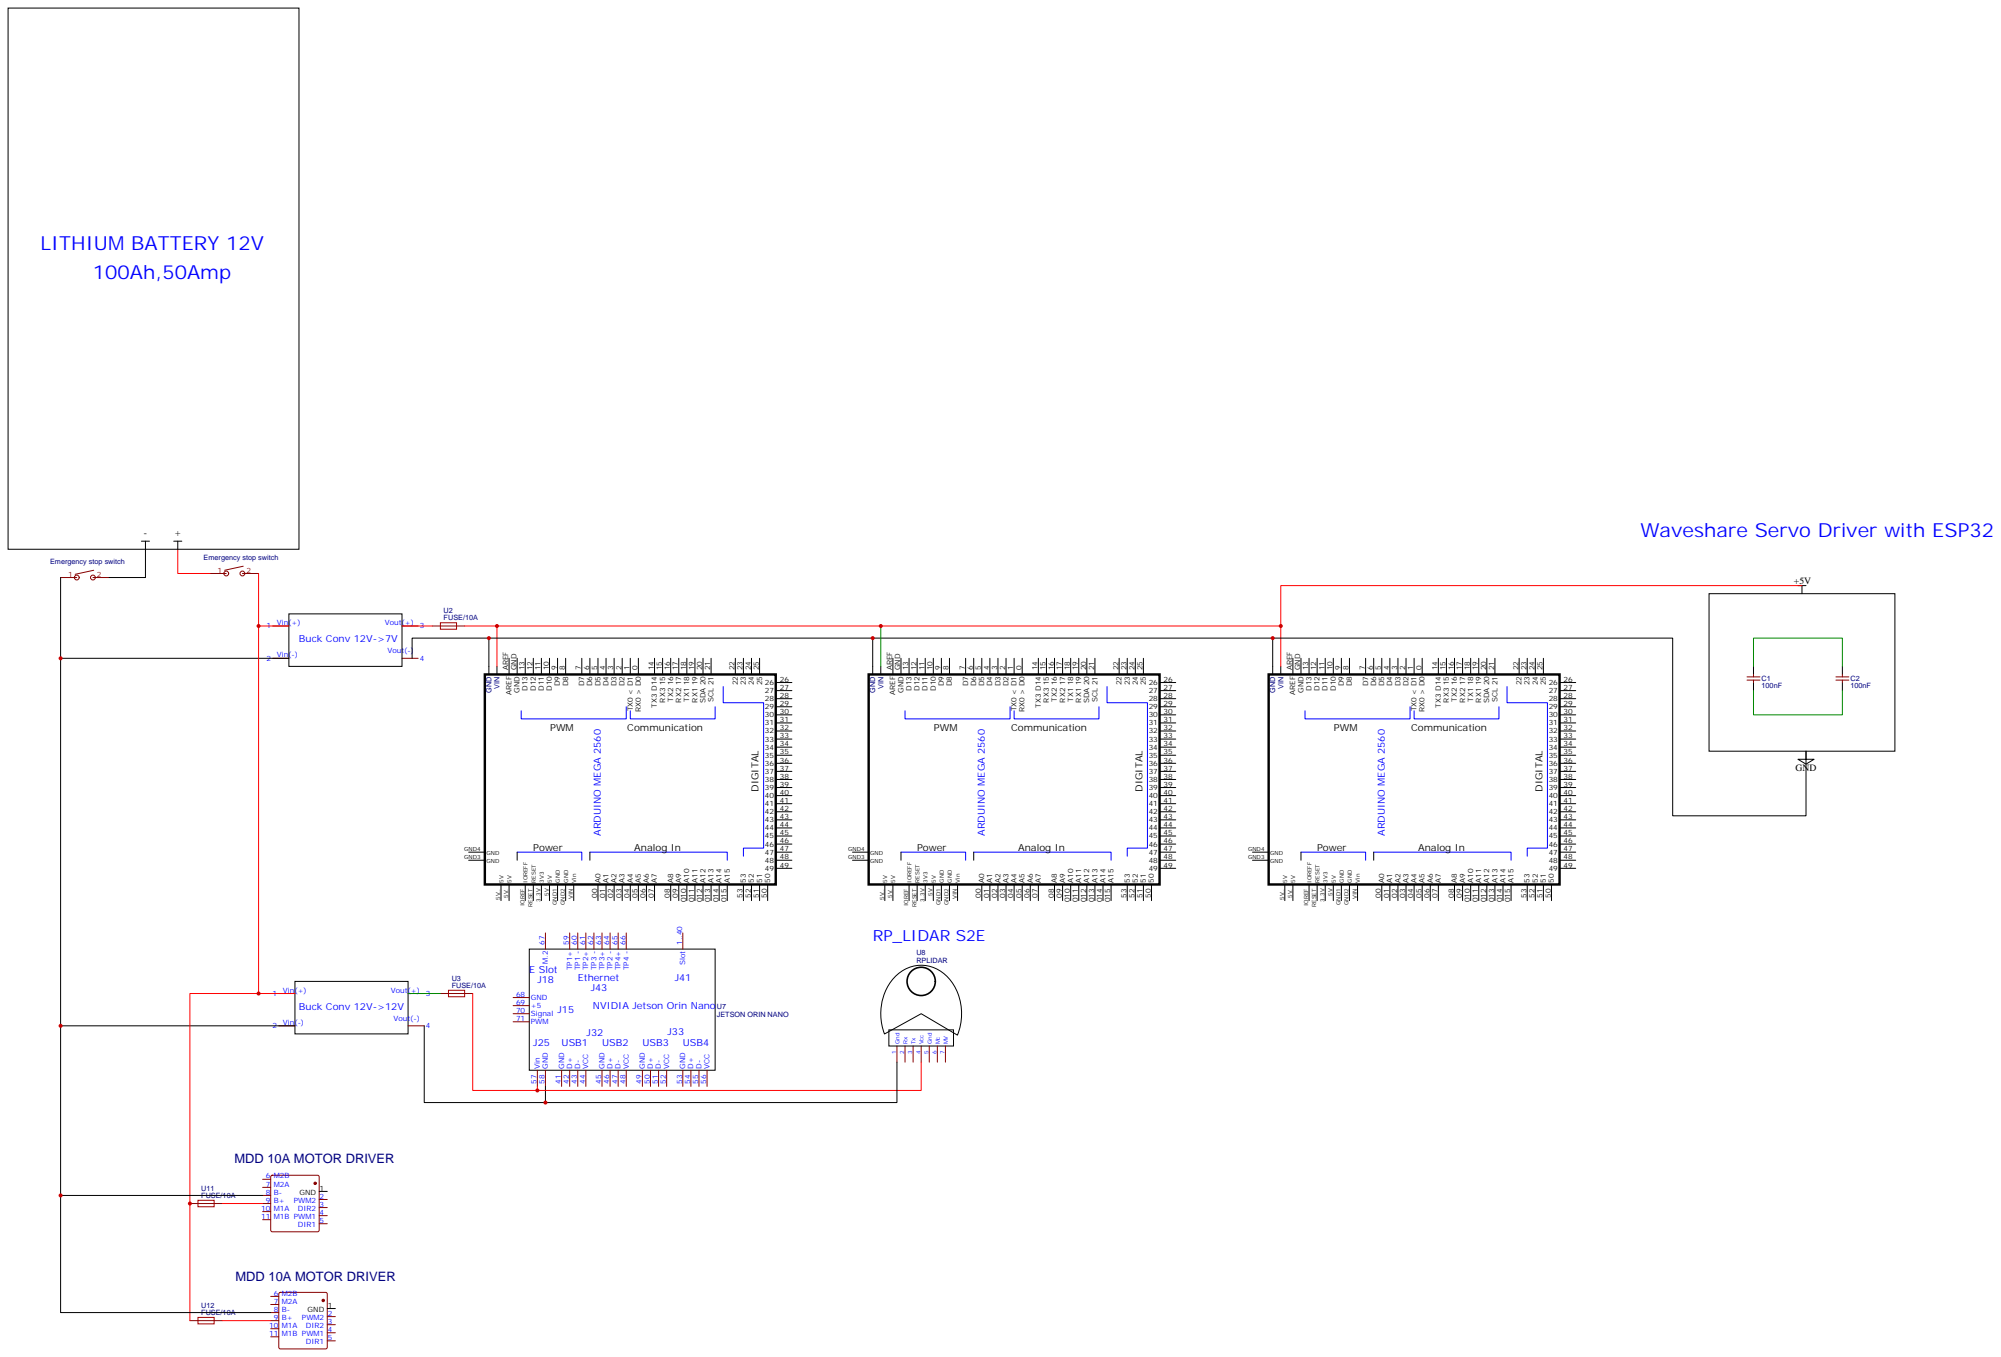
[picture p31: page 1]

Waveshare Servo Driver with ESP32

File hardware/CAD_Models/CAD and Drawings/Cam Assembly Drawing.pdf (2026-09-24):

50 10 R1

38.2 Ø4.5 Ø24Ø20 | M5X10 Bolt | M3 Nut

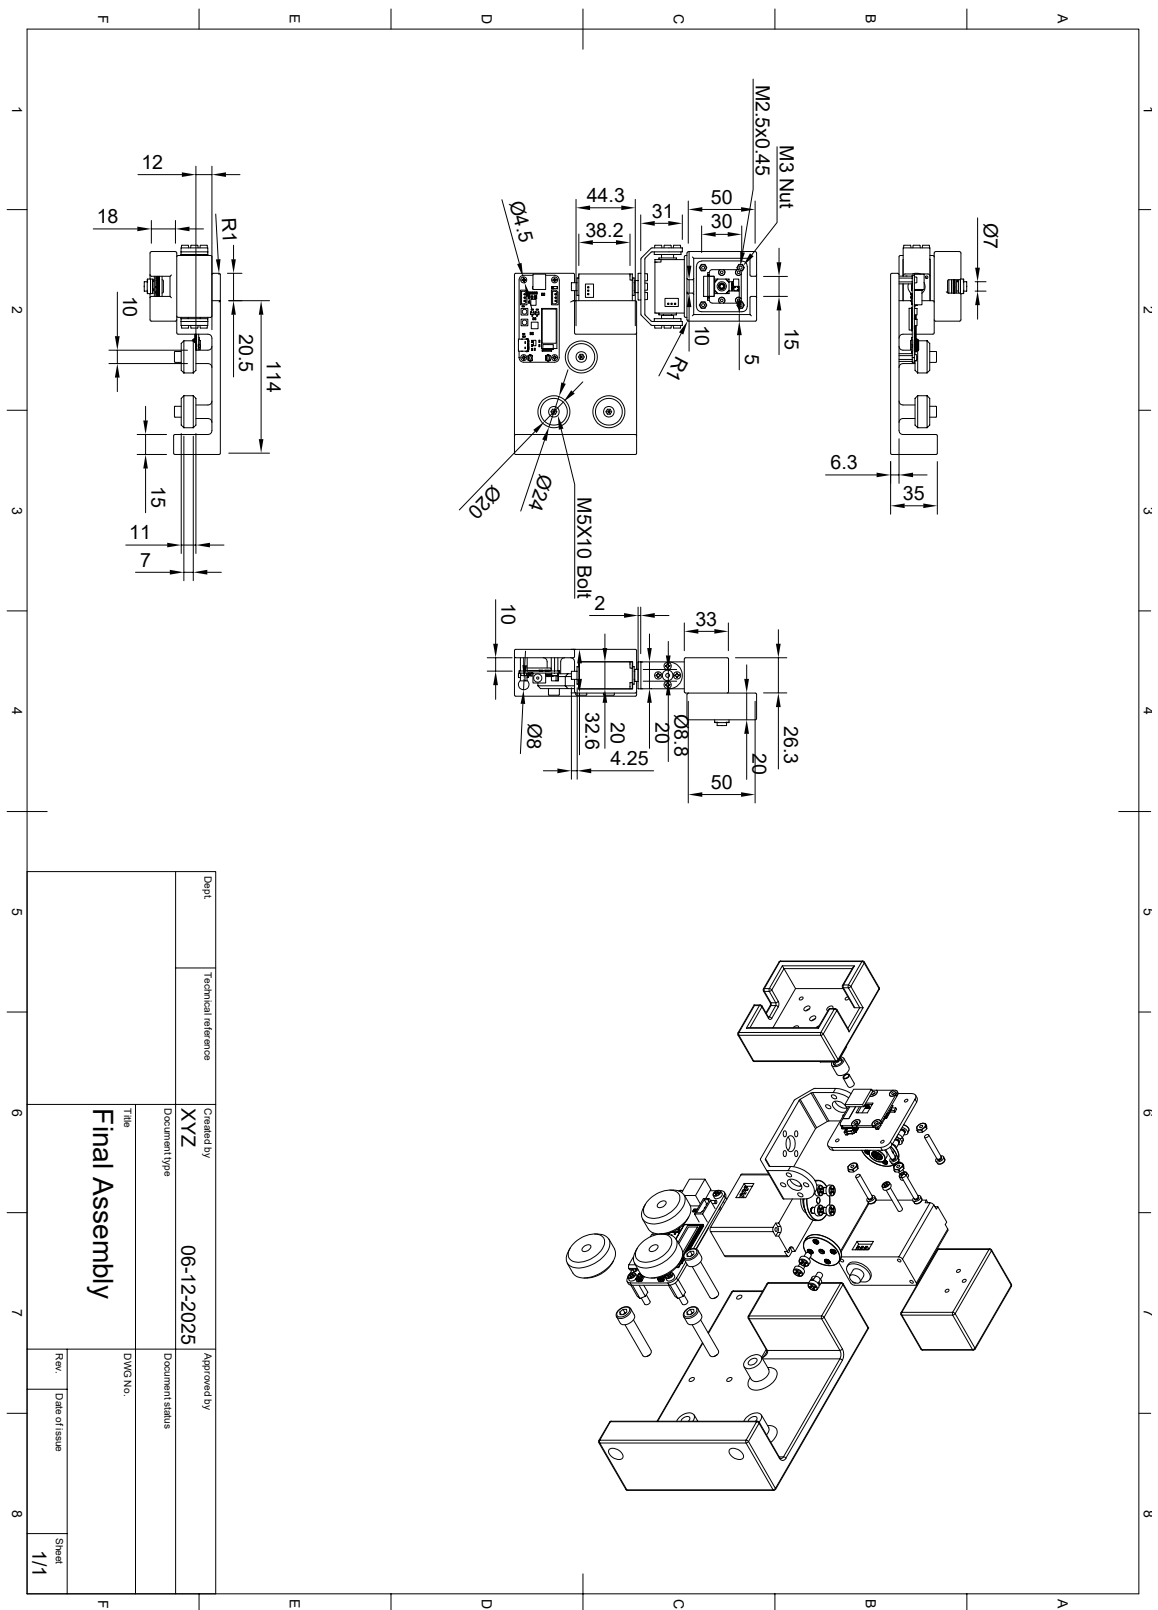
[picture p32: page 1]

1 A 2 3 4 5 6 7 8 1 2 3 4 5 6 7 8 FEDCB FEDCBA Dept. Technical reference Created by Approved by Title DWG No. Document type Document status Rev. Date of issue Sheet 06-12-2025 1/1 Final Assembly XYZ

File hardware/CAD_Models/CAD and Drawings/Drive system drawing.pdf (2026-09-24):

400

448.43 550 8 | 170 M5 Nut M4 Nut | 20

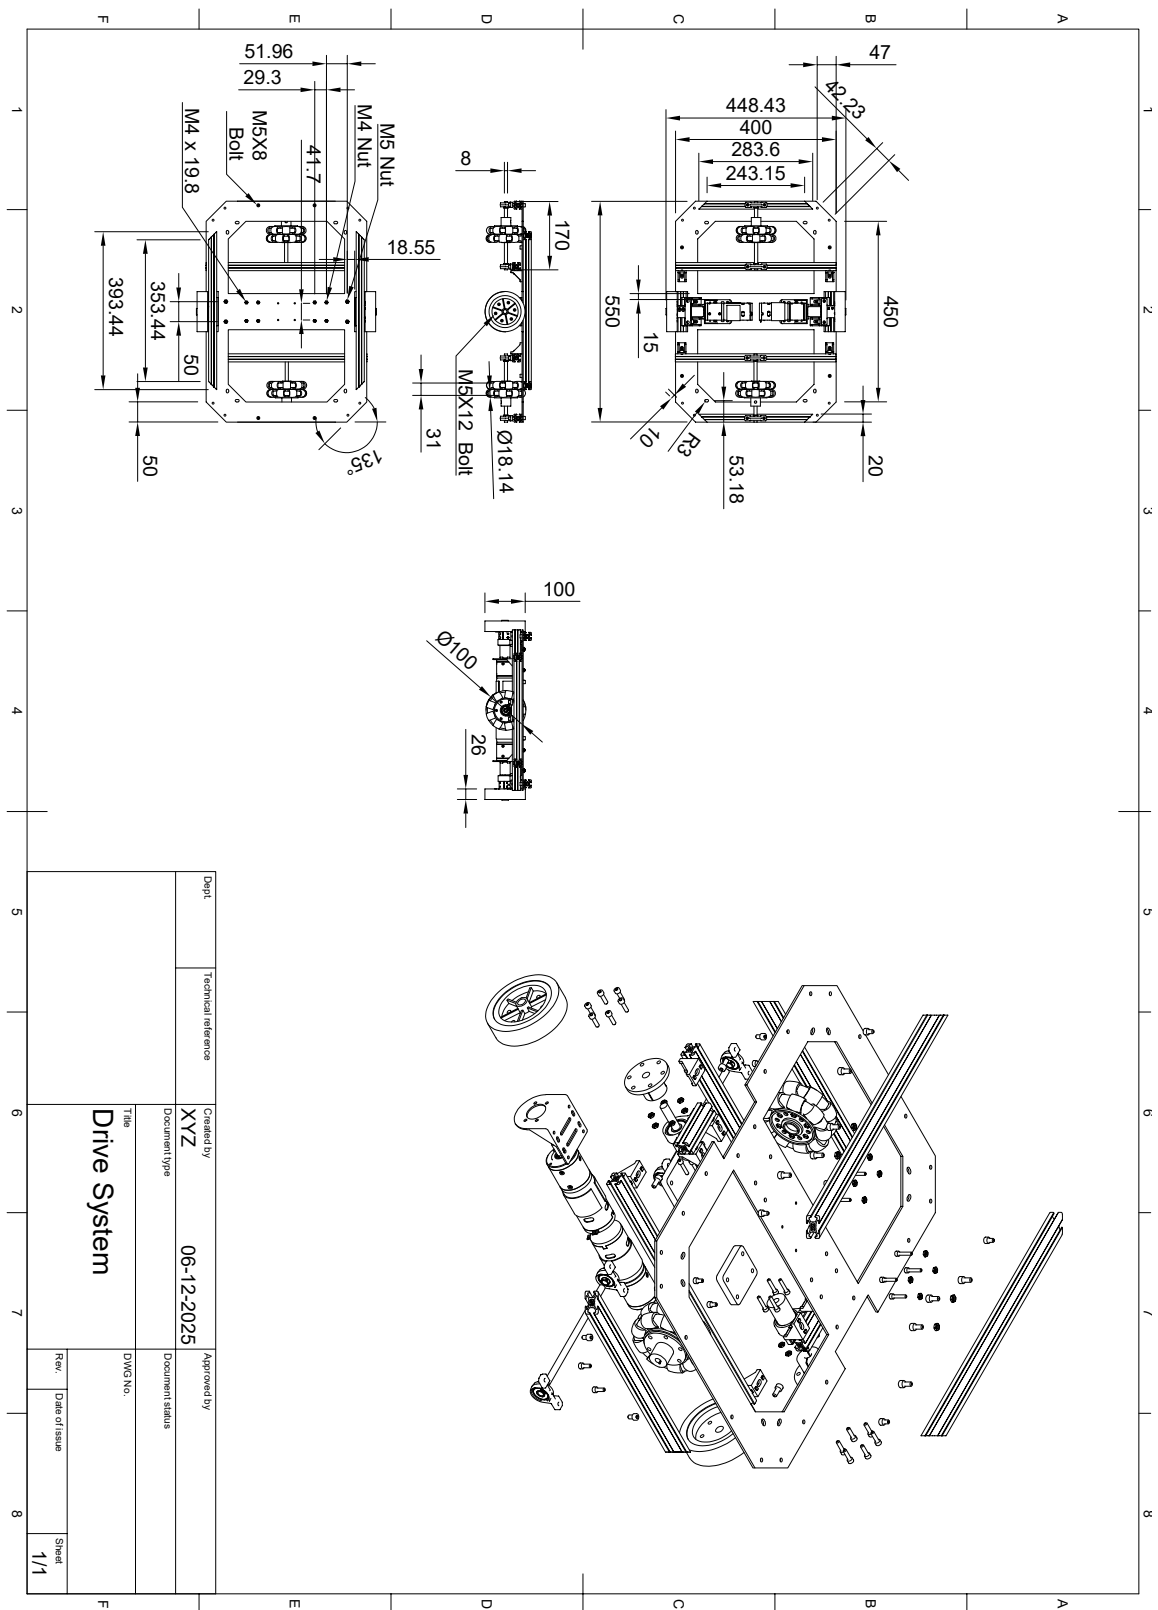
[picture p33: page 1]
53.18 10 M5X8 Bolt M4 x 19.8; 18.55 M5X12 Bolt 31

1 A 2 3 4 5 6 7 8 1 2 3 4 5 6 7 8 FEDCB FEDCBA Dept. Technical reference Created by Approved by Title DWG No. Document type Document status Rev. Date of issue Sheet 06-12-2025 1/1 Drive System XYZ 450

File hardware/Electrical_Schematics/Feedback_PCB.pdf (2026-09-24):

A | A

1

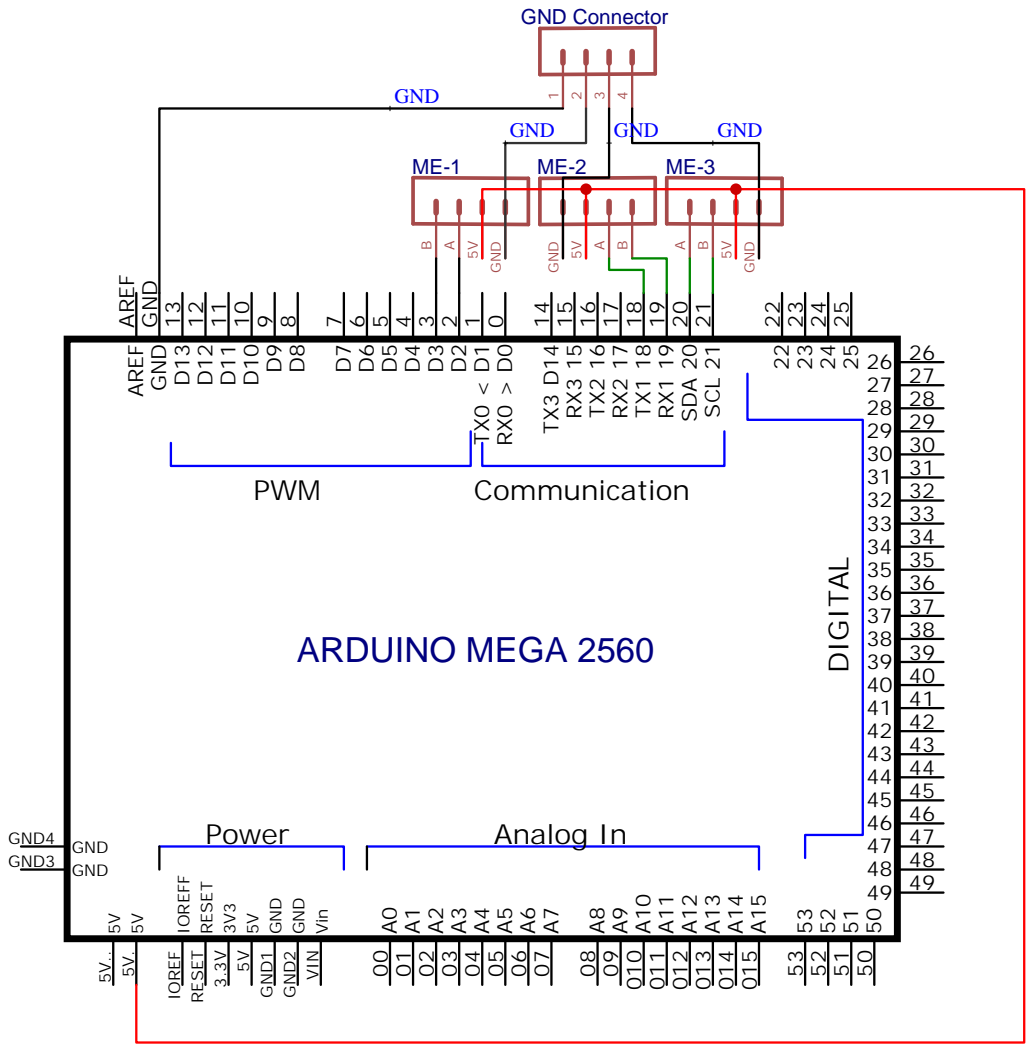
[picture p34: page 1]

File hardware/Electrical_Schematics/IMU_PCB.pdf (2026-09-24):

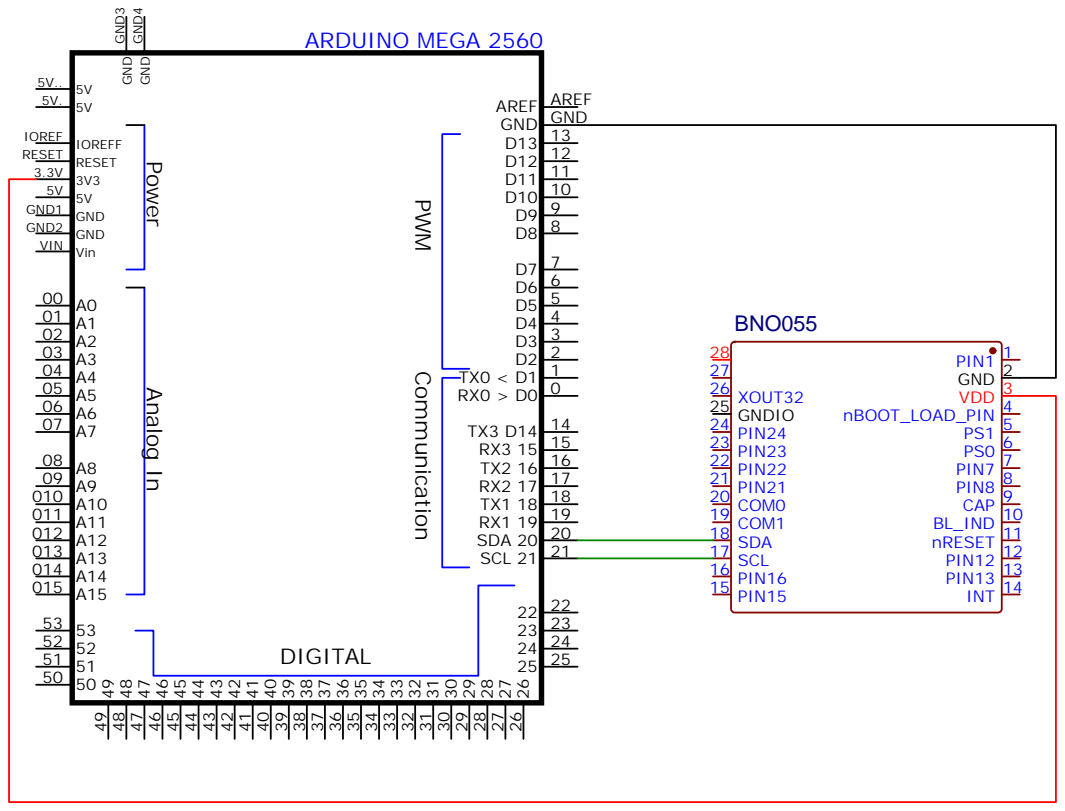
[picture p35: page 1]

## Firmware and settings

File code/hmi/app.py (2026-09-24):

import os
import csv
import threading
from datetime import datetime, timedelta
from flask import Flask, render_template, request, jsonify, session, redirect, url_for
import sys
import subprocess

app = Flask(__name__)
app.secret_key = 'super_secret_rover_key_change_this'
# Make session cookies permanent for a long duration (approx 1 year)
# This keeps users logged in until they explicitly logout or clear cookies.
app.permanent_session_lifetime = timedelta(days=365)
# Force UTF-8 safe printing
if hasattr(sys.stdout, "reconfigure"):
    sys.stdout.reconfigure(encoding='utf-8')

# -------------------------
# Config / Filenames
# -------------------------
ROVER_FILE = './data/rover_data.csv'
INVENTORY_FILE = './data/inventory.csv'   # stores inventory scan logs
RACKS_FILE = './data/racks.csv'           # stores known racks and their shelf counts

# Vision node path (for Jetson Nano)
vision_node_path = './ros_workspace/src/warehouse_scanning/scripts'
sys.path.insert(0, vision_node_path)

# CSV headers
ROVER_HEADERS = ['round_id', 'timestamp', 'battery_level', 'cpu_temp', 'status', 'current_task', 'coordinates']
INVENTORY_HEADERS = ['round_id', 'timestamp', 'shelf_id', 'shelf_status']
RACKS_HEADERS = ['rack_id', 'shelves', 'created_at']

# Defaults
DEFAULT_RACK_COUNT = 5
DEFAULT_SHELVES_PER_RACK = 5
DEFAULT_RACK_IDS = ['R01', 'R02', 'R03', 'R04', 'R05']

file_lock = threading.Lock()
CURRENT_ROUND_ID = 0

# Flask app initialization
app = Flask(__name__)
app.secret_key = 'super_secret_rover_key_change_this'


# -------------------------
# Helper functions
# -------------------------
def init_db():
    """Initialize CSV files and detect last round_id."""
    global CURRENT_ROUND_ID

    # Rover file
    if not os.path.exists(ROVER_FILE):
        with open(ROVER_FILE, 'w', newline='') as f:
            writer = csv.writer(f)
            writer.writerow(ROVER_HEADERS)

    # Inventory file
    if not os.path.exists(INVENTORY_FILE):
        with open(INVENTORY_FILE, 'w', newline='') as f:
            writer = csv.writer(f)
            writer.writerow(INVENTORY_HEADERS)

    # Racks file
    if not os.path.exists(RACKS_FILE):
        with open(RACKS_FILE, 'w', newline='') as f:
            writer = csv.writer(f)
            writer.writerow(RACKS_HEADERS)

    # Detect last round from rover logs
    try:
        with open(ROVER_FILE, 'r') as f:
            reader = csv.DictReader(f)
            rounds = [int(row['round_id']) for row in reader if row.get('round_id', '').isdigit()]
            CURRENT_ROUND_ID = max(rounds) if rounds else 1
    except:
        CURRENT_ROUND_ID = 1


def read_racks():
    """Return dict: rack_id -> shelves"""
    racks = {}
    if not os.path.exists(RACKS_FILE):
        return racks
    with open(RACKS_FILE, 'r', newline='') as f:
        reader = csv.DictReader(f)
        for r in reader:
            rid = r.get('rack_id')
            if not rid:
                continue
            try:
                shelves = int(r.get('shelves', DEFAULT_SHELVES_PER_RACK))
            except:
                shelves = DEFAULT_SHELVES_PER_RACK
            racks[rid] = shelves
    return racks


def write_racks(racks_dict):
    """Write racks to racks.csv"""
    with open(RACKS_FILE, 'w', newline='') as f:
        writer = csv.DictWriter(f, fieldnames=RACKS_HEADERS)
        writer.writeheader()
        for rid, shelves in racks_dict.items():
            row = {
                'rack_id': rid,
                'shelves': shelves,
                'created_at': datetime.now().strftime('%Y-%m-%d %H:%M:%S')
            }
            writer.writerow(row)


def ensure_default_racks():
    """Make sure default 5 racks exist."""
    racks = read_racks()

    if len(racks) >= DEFAULT_RACK_COUNT:
        return

    added = False
    for rid in DEFAULT_RACK_IDS[:DEFAULT_RACK_COUNT]:
        if rid not in racks:
            racks[rid] = DEFAULT_SHELVES_PER_RACK
            added = True

    if added:
        write_racks(racks)


# Initialize everything
init_db()
ensure_default_racks()


# -------------------------
# Authentication
# -------------------------
def login_required(func):
    def wrapper(*args, **kwargs):
        if 'logged_in' not in session:
            return redirect(url_for('login'))
        return func(*args, **kwargs)
    wrapper.__name__ = func.__name__
    return wrapper


# -------------------------
# Routes
# -------------------------
@app.route('/')
def index():
    if 'logged_in' in session:
        return redirect(url_for('dashboard'))
    return redirect(url_for('login'))


@app.route('/login', methods=['GET', 'POST'])
def login():
    error = None
    if request.method == 'POST':
        username = request.form.get('username')
        password = request.form.get('password')
        if username == 'admin' and password == 'password':
            # Mark this session as permanent so it persists long-term
            session.permanent = True
        if request.form.get('username') == 'admin' and request.form.get('password') == 'password':
            session['logged_in'] = True
            return redirect(url_for('dashboard'))
        error = 'Invalid Credentials.'
    return render_template('login.html', error=error)


@app.route('/logout')
def logout():
    session.pop('logged_in', None)
    return redirect(url_for('login'))


@app.route('/dashboard')
@login_required
def dashboard():
    return render_template('dashboard.html')


# -------------------------
# API: Manual new round
# -------------------------
@app.route('/api/new_round', methods=['POST'])
@login_required
def new_round():
    global CURRENT_ROUND_ID
    with file_lock:
        CURRENT_ROUND_ID += 1
    print("New round started:", CURRENT_ROUND_ID)
    return jsonify({"message": "New round started", "new_round_id": CURRENT_ROUND_ID})


# -------------------------
# API: Rover Update
# -------------------------
@app.route('/api/update', methods=['POST'])
def update_data():
    global CURRENT_ROUND_ID

    try:
        data = request.get_json()
        print("Received data from rover:", data)
        if not data:
            return jsonify({"error": "No JSON data"}), 400

        # Handle new round flag
        if data.get('new_round') is True:
            with file_lock:
                CURRENT_ROUND_ID += 1
            print("New round initialized by rover:", CURRENT_ROUND_ID)

        timestamp = datetime.now().strftime('%Y-%m-%d %H:%M:%S')

        # Telemetry row
        telemetry_row = [
            CURRENT_ROUND_ID,
            timestamp,
            data.get('battery_level', 'N/A'),
            data.get('cpu_temp', 'N/A'),
            data.get('status', 'Idle'),
            data.get('current_task', 'None'),
            data.get('coordinates', '0,0')
        ]

        with file_lock:
            # Write telemetry
            with open(ROVER_FILE, 'a', newline='') as f:
                writer = csv.writer(f)
                writer.writerow(telemetry_row)

            if data.get('round_id'):
                CURRENT_ROUND_ID = int(data.get('round_id'))
            # Handle inventory scan
            if data.get('payload'):
                payload = data.get('payload', '')
                payload_list = payload.split('_')
                if len(payload_list) != 2:
                    r_part=payload_list[0]
                    s_part=payload_list[1]
                    i_part=payload_list[2]

                shelf_id=r_part+ '-' + '0' + s_part[1:]
                if payload:
                    shelf_status = i_part
                else:
                    shelf_status = "Unknown"
                    
                if shelf_id:
                    rack_part = shelf_id.split('-')[0] if '-' in shelf_id else shelf_id

                    # auto-create rack if missing
                    racks = read_racks()
                    rack_created = False
                    if rack_part not in racks:
                        racks[rack_part] = DEFAULT_SHELVES_PER_RACK
                        write_racks(racks)
                        print("Auto-created new rack:", rack_part)
                        rack_created = True

                    # Write inventory entry
                    inventory_row = [
                        CURRENT_ROUND_ID,
                        timestamp,
                        shelf_id,
                        shelf_status
                    ]
                    with open(INVENTORY_FILE, 'a', newline='') as f:
                        writer = csv.writer(f)
                        writer.writerow(inventory_row)

        return jsonify({"message": "Logged", "round_id": CURRENT_ROUND_ID, "rack_created": rack_created if 'rack_created' in locals() else False}), 200

    except Exception as e:
        return jsonify({"error": str(e)}), 500


# -------------------------
# API: Get Shelves (paginated)
# -------------------------
@app.route('/api/get_shelves', methods=['GET'])
@login_required
def get_shelves():
    """
    Paginated shelves for a given rack.
    Query params:
      - rack (required): rack id, e.g. A or G
      - offset (optional): integer offset (default 0)
      - limit  (optional): integer page size (default 5)
      - round_id (optional): which round to read inventory from (defaults to current round)
    """
    rack = request.args.get('rack')
    if not rack:
        return jsonify({"error": "missing rack parameter"}), 400

    try:
        offset = max(0, int(request.args.get('offset', 0)))
    except:
        offset = 0
    try:
        limit = max(1, int(request.args.get('limit', 5)))
    except:
        limit = 5

    # which round to view
    req_round = request.args.get('round_id')
    try:
        target_round = int(req_round) if req_round else CURRENT_ROUND_ID
    except:
        target_round = CURRENT_ROUND_ID

    # Get known shelves count for this rack from racks.csv
    racks = read_racks()
    shelves_count = int(racks.get(rack, DEFAULT_SHELVES_PER_RACK))

    # Build full list of shelf ids in natural order
    full_shelves = [f"{rack}-{i:02d}" for i in range(1, shelves_count + 1)]
    total = len(full_shelves)

    # read latest statuses for shelves (prefer entries for the target round)
    shelf_status_map = {}
    try:
        with file_lock:
            if os.path.exists(INVENTORY_FILE):
                with open(INVENTORY_FILE, 'r', newline='') as f:
                    reader = csv.DictReader(f)
                    # iterate and keep last status per shelf for the requested round
                    for row in reader:
                        try:
                            r_id = int(row.get('round_id', '1'))
                        except:
                            r_id = 1
                        if r_id != target_round:
                            continue
                        sid = row.get('shelf_id')
                        if sid:
                            shelf_status_map[sid] = row.get('shelf_status', 'Unknown')
    except Exception:
        pass

    # Build the page slice
    slice_shelves = full_shelves[offset: offset + limit]
    out = []
    for idx, sid in enumerate(slice_shelves, start=offset + 1):
        out.append({
            "shelf_id": sid,
            "index": idx,
            "status": shelf_status_map.get(sid, "Unknown")
        })

    return jsonify({
        "rack": rack,
        "total": total,
        "offset": offset,
        "limit": limit,
        "shelves": out
    })


# -------------------------
# API: Get Dashboard Data
# -------------------------
@app.route('/api/get_data', methods=['GET'])
@login_required
def get_data():
    req_round_id = request.args.get('round_id')
    try:
        target_round = int(req_round_id) if req_round_id else CURRENT_ROUND_ID
    except:
        target_round = CURRENT_ROUND_ID

    logs = []
    inventory_logs = []
    rounds_available = set()

    try:
        with file_lock:

            # Load telemetry logs
            if os.path.exists(ROVER_FILE):
                with open(ROVER_FILE, 'r') as f:
                    reader = csv.DictReader(f)
                    for row in reader:
                        try:
                            r_id = int(row.get('round_id', '1'))
                        except:
                            r_id = 1
                        rounds_available.add(r_id)
                        if r_id == target_round:
                            logs.append(row)

            # Load inventory logs
            if os.path.exists(INVENTORY_FILE):
                with open(INVENTORY_FILE, 'r') as f:
                    reader = csv.DictReader(f)
                    for row in reader:
                        try:
                            r_id = int(row.get('round_id', '1'))
                        except:
                            r_id = 1
                        if r_id == target_round:
                            inventory_logs.append(row)

        latest = logs[-1] if logs else {}

        # compute uptime
        uptime = "00:00:00"
        start_time_str = "N/A"
        last_scan_str = inventory_logs[-1]['timestamp'] if inventory_logs else "N/A"

        if logs:
            fmt = '%Y-%m-%d %H:%M:%S'
            try:
                start = datetime.strptime(logs[0]['timestamp'], fmt)
                end = datetime.strptime(logs[-1]['timestamp'], fmt) if target_round != CURRENT_ROUND_ID else datetime.now()
                uptime = str(end - start).split('.')[0]
                start_time_str = logs[0]['timestamp']
            except:
                pass

        # Load racks dynamically
        racks = read_racks()
        if not racks:
            racks = {'A': 5, 'B': 5, 'C': 5, 'D': 5, 'E': 5}

        # Build scanned shelf map
        scanned_shelves_map = {}
        for rack, count in racks.items():
            for i in range(1, count + 1):
                sid = f"{rack}-{i:02d}"
                scanned_shelves_map[sid] = "Unknown"

        for row in inventory_logs:
            sid = row['shelf_id']
            scanned_shelves_map[sid] = row['shelf_status']

        empty_shelves = [sid for sid, status in scanned_shelves_map.items() if status.lower() == "empty"]

        # Build combined logs
        combined_logs = logs[:]
        for irow in inventory_logs:
            combined_logs.append({
                'timestamp': irow['timestamp'],
                'status': 'SCANNED',
                'current_task': 'Inventory Update',
                'coordinates': '--',
                'shelf_id': irow['shelf_id'],
                'shelf_status': irow['shelf_status'],
                'battery_level': '-',
                'cpu_temp': '-'
            })
        combined_logs.sort(key=lambda x: x.get('timestamp', ''))

        return jsonify({
            "current_round_id": CURRENT_ROUND_ID,
            "viewing_round_id": target_round,
            "available_rounds": sorted(list(rounds_available), reverse=True),
            "vitals": latest,
            "stats": {
                "uptime": uptime,
                "start_time": start_time_str,
                "last_scan": last_scan_str,
                "empty_shelves": empty_shelves,
                "scanned_shelves_map": scanned_shelves_map,
                "racks": racks
            },
            "logs": combined_logs[-20:][::-1]
        })

    except Exception as e:
        return jsonify({"error": str(e)}), 500


# -------------------------
# API: get racks
# -------------------------
@app.route('/api/get_racks', methods=['GET'])
@login_required
def get_racks():
    try:
        return jsonify({"racks": read_racks()})
    except Exception as e:
        return jsonify({"error": str(e)}), 500


# -------------------------
# API: Vision Control (Jetson Nano)
# -------------------------
# Global reference to vision node
_vision_node = None

def init_vision_node():
    """Initialize vision node on first request"""
    global _vision_node
    if _vision_node is None:
        try:
            import sys
            import visionNode
            sys.path.insert(0, vision_node_path)
            
            _vision_node = visionNode.get()
        except Exception as e:
            print(f"Failed to initialize vision node: {e}")
            return None
    return _vision_node


@app.route('/api/vision/capture', methods=['POST'])
@login_required
def vision_capture():
    """
    Capture with scanning modes
    JSON params:
      - x: float (default 0.0)
      - y: float (default 0.0)
      - mode: "normal" | "top" | "bottom" | "full_sweep" (default "normal")
    """
    try:
        data = request.get_json() or {}
        x = float(data.get('x', 0.0))
        y = float(data.get('y', 0.0))
        mode = data.get('mode', 'normal').lower()
        
        vision = init_vision_node()
        if vision is None:
            return jsonify({"error": "Vision node not initialized"}), 500
        
        # Map modes to capture parameters
        is_top = mode in ['top', 'full_sweep']
        is_bottom = mode in ['bottom', 'full_sweep']
        
        vision.capture(x=x, y=y, isTop=is_top, isBottom=is_bottom)
        
        return jsonify({
            "status": "success",
            "message": f"Capture initiated: mode={mode}, x={x}, y={y}",
            "mode": mode
        }), 200
        
    except Exception as e:
        return jsonify({"error": str(e)}), 500


@app.route('/api/vision/capture_once', methods=['POST'])
@login_required
def vision_capture_once():
    """
    Single frame capture at specific orientation
    JSON params:
      - x: float (default 0.0)
      - y: float (default 0.0)
      - orientation: int 0=bottom, 1=normal, 2=top (default 1)
    """
    try:
        data = request.get_json() or {}
        x = float(data.get('x', 0.0))
        y = float(data.get('y', 0.0))
        orientation = int(data.get('orientation', 1))
        
        vision = init_vision_node()
        if vision is None:
            return jsonify({"error": "Vision node not initialized"}), 500
        
        vision.capture_once(x=x, y=y, orientation=orientation)
        
        return jsonify({
            "status": "success",
            "message": f"Single capture initiated at orientation {orientation}"
        }), 200
        
    except Exception as e:
        return jsonify({"error": str(e)}), 500


@app.route('/api/vision/led', methods=['POST'])
@login_required
def vision_led():
    """
    Control LED
    JSON params:
      - color: "red" | "green" | "yellow" | "white" | "blue" etc. (default "white")
      - level: "low" | "med" | "high" (default "low")
      - index: int (default 0)
      - action: "on" | "off" (default "on")
    """
    try:
        data = request.get_json() or {}
        action = data.get('action', 'on').lower()
        color = data.get('color', 'white')
        level = data.get('level', 'low')
        index = int(data.get('index', 0))
        
        vision = init_vision_node()
        if vision is None:
            return jsonify({"error": "Vision node not initialized"}), 500
        
        if action == 'off':
            success = vision.led_off(index=index)
            msg = f"LED {index} turned off"
        else:
            success = vision.led(color=color, level=level, index=index)
            msg = f"LED {index} set to {color} ({level})"
        
        if success:
            return jsonify({"status": "success", "message": msg}), 200
        else:
            return jsonify({"error": "LED command failed"}), 500
        
    except Exception as e:
        return jsonify({"error": str(e)}), 500


@app.route('/api/vision/servo_debug', methods=['POST'])
@login_required
def vision_servo_debug():
    """
    Open servo debug terminal (from servoCLI.py)
    """
    try:
        vision = init_vision_node()
        if vision is None:
            return jsonify({"error": "Vision node not initialized"}), 500
        
        # Start servo debug in background
        vision.scanner.open_servo_debug_terminal()
        
        return jsonify({
            "status": "success",
            "message": "Servo debug terminal opened"
        }), 200
        
    except Exception as e:
        return jsonify({"error": str(e)}), 500


@app.route('/api/vision/wait_completion', methods=['POST'])
@login_required
def vision_wait_completion():
    """
    Wait for all image processing to complete
    JSON params:
      - quiet: bool (default false)
    """
    try:
        data = request.get_json() or {}
        quiet = data.get('quiet', False)
        
        vision = init_vision_node()
        if vision is None:
            return jsonify({"error": "Vision node not initialized"}), 500
        
        vision.wait_until_done(quiet=quiet)
        
        return jsonify({
            "status": "success",
            "message": "All processing completed"
        }), 200
        
    except Exception as e:
        return jsonify({"error": str(e)}), 500


# -------------------------
# Run Server
# -------------------------
if __name__ == '__main__':
    app.run(debug=True, host='0.0.0.0', port=8000)

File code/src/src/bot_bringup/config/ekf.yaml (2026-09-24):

### ekf config file ###
ekf_filter_node:
    ros__parameters:

        # use_sim_time: true

        
# The frequency, in Hz, at which the filter will output a position estimate. Note that the filter will not begin
# computation until it receives at least one message from one of the inputs. It will then run continuously at the
# frequency specified here, regardless of whether it receives more measurements. Defaults to 30 if unspecified.
        frequency: 10.0

# The period, in seconds, after which we consider a sensor to have timed out. In this event, we carry out a predict
# cycle on the EKF without correcting it. This parameter can be thought of as the minimum frequency with which the
# filter will generate new output. Defaults to 1 / frequency if not specified.
        sensor_timeout: 0.1

# ekf_localization_node and ukf_localization_node both use a 3D omnidirectional motion model. If this parameter is
# set to true, no 3D information will be used in your state estimate. Use this if you are operating in a planar
# environment and want to ignore the effect of small variations in the ground plane that might otherwise be detected
# by, for example, an IMU. Defaults to false if unspecified.
        two_d_mode: true

# Use this parameter to provide an offset to the transform generated by ekf_localization_node. This can be used for
# future dating the transform, which is required for interaction with some other packages. Defaults to 0.0 if
# unspecified.
        transform_time_offset: 0.0

# Use this parameter to provide specify how long the tf listener should wait for a transform to become available. 
# Defaults to 0.0 if unspecified.
        transform_timeout: 0.0

# If you're having trouble, try setting this to true, and then echo the /diagnostics_agg topic to see if the node is
# unhappy with any settings or data.
        print_diagnostics: true

# Debug settings. Not for the faint of heart. Outputs a ludicrous amount of information to the file specified by
# debug_out_file. I hope you like matrices! Please note that setting this to true will have strongly deleterious
# effects on the performance of the node. Defaults to false if unspecified.
        debug: false

# Defaults to "robot_localization_debug.txt" if unspecified. Please specify the full path.
        debug_out_file: /path/to/debug/file.txt

# Whether to broadcast the transformation over the /tf topic. Defaults to true if unspecified.
        publish_tf: true

# Whether to publish the acceleration state. Defaults to false if unspecified.
        publish_acceleration: false

# If the filter sees a jump back in time, the filter is reset (convenient for testing with rosbags!)
        reset_on_time_jump: true

# REP-105 (http://www.ros.org/reps/rep-0105.html) specifies four principal coordinate frames: base_link, odom, map, and
# earth. base_link is the coordinate frame that is affixed to the robot. Both odom and map are world-fixed frames.
# The robot's position in the odom frame will drift over time, but is accurate in the short term and should be
# continuous. The odom frame is therefore the best frame for executing local motion plans. The map frame, like the odom
# frame, is a world-fixed coordinate frame, and while it contains the most globally accurate position estimate for your
# robot, it is subject to discrete jumps, e.g., due to the fusion of GPS data or a correction from a map-based
# localization node. The earth frame is used to relate multiple map frames by giving them a common reference frame.
# ekf_localization_node and ukf_localization_node are not concerned with the earth frame.
# Here is how to use the following settings:
# 1. Set the map_frame, odom_frame, and base_link frames to the appropriate frame names for your system.
#     1a. If your system does not have a map_frame, just remove it, and make sure "world_frame" is set to the value of
#         odom_frame.
# 2. If you are fusing continuous position data such as wheel encoder odometry, visual odometry, or IMU data, set
#   "world_frame" to your odom_frame value. This is the default behavior for robot_localization's state estimation nodes.
# 3. If you are fusing global absolute position data that is subject to discrete jumps (e.g., GPS or position updates
# from landmark observations) then:
#     3a. Set your "world_frame" to your map_frame value
#     3b. MAKE SURE something else is generating the odom->base_link transform. Note that this can even be another state
#         estimation node from robot_localization! However, that instance should *not* fuse the global data.
        map_frame: map                   # Defaults to "map" if unspecified
        odom_frame: odom                 # Defaults to "odom" if unspecified
        base_link_frame: base_link  # Defaults to "base_link" if unspecified
        world_frame: odom                # Defaults to the value of odom_frame if unspecified
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

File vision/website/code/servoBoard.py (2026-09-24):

import serial
import time
import re

# ==========================================
# PART 1: DRIVER CLASS + LED API
# ==========================================
class ServoBoard:
    # -------------------------------------------------
    # Predefined colors for easy use
    # -------------------------------------------------
    COLOR_MAP = {
        # --- Basic Colors ---
        'r': (255, 0, 0), 'red': (255, 0, 0),
        'g': (0, 255, 0), 'green': (0, 255, 0),
        'b': (0, 0, 255), 'blue': (0, 0, 255),
        'y': (255, 255, 0), 'yellow': (255, 255, 0),
        'w': (255, 255, 255), 'white': (255, 255, 255),
        'cyan': (0, 255, 255),
        'magenta': (255, 0, 255),
        'orange': (255, 165, 0),
        'off': (0, 0, 0),

        # -------------------------------------------------
        # OFFICIAL SIGNAL COLORS (HEX → RGB)
        # -------------------------------------------------

        # Signal Yellow (Warning) #F9A800
        'signal_yellow': (249, 168, 0),
        'sy': (249, 168, 0),

        # Signal Red (Danger / Prohibition) #9B2423
        'signal_red': (155, 36, 35),
        'sr': (155, 36, 35),

        # Signal Blue (Mandatory) #005387
        'signal_blue': (0, 83, 135),
        'sb': (0, 83, 135),

        # Signal Green (Safe Condition / Exit) #237F52
        'signal_green': (35, 127, 82),
        'sg': (35, 127, 82),

        # White background #ECECE7
        'signal_white': (236, 236, 231),
        'sw': (236, 236, 231),

        # Black contrast #2B2B2C
        'signal_black': (43, 43, 44),
        'sblk': (43, 43, 44),
    }

    def __init__(self, port, baudrate=115200, timeout=2):
        try:
            self.ser = serial.Serial(port, baudrate, timeout=timeout)
            print(f"Connected to {port} at {baudrate} baud.")
            time.sleep(2)
            self.clear_buffer()
        except serial.SerialException as e:
            print(f"Error connecting to serial port: {e}")
            self.ser = None

    def clear_buffer(self):
        if self.ser and self.ser.in_waiting:
            self.ser.read(self.ser.in_waiting)

    # ---------------------------------------------------------
    # SERVO MOVEMENT
    # ---------------------------------------------------------
    def move(self, servo_id, angle):
        if not self.ser:
            return
        angle = max(0, min(180, angle))
        cmd = f"{servo_id} {angle}\n"
        self.ser.write(cmd.encode())
        time.sleep(0.01)

    def calibrate(self, servo_id):
        if not self.ser:
            return
        cmd = f"{servo_id} -1\n"
        self.ser.write(cmd.encode())
        time.sleep(0.5)

    def get_positions(self):
        if not self.ser:
            return {}
        self.clear_buffer()
        self.ser.write(b"P\n")

        angles = {}
        start = time.time()

        while time.time() - start < 1.0:
            if self.ser.in_waiting:
                try:
                    line = self.ser.readline().decode().strip()
                    match = re.search(r"ID (\d+): ([\d\.-]+) deg", line)
                    if match:
                        s_id = int(match.group(1))
                        s_ang = float(match.group(2))
                        angles[s_id] = s_ang

                    if 0 in angles and 1 in angles:
                        break
                except:
                    pass
        return angles

    # ---------------------------------------------------------
    # LOW-LEVEL LED COMMAND
    # ---------------------------------------------------------
    def LED(self, index=0, r=255, g=255, b=255, brightness=int(255*0.7)):
        if not self.ser:
            print("[ERROR] Servo board not initialized.")
            return

        cmd = f"L {index} {r} {g} {b} {brightness}\n"
        print("Sending LED command:", repr(cmd))
        self.ser.write(cmd.encode())
        time.sleep(0.05)

    # ---------------------------------------------------------
    # NEW HIGH-LEVEL LED API
    # ---------------------------------------------------------
    def _normalize_color(self, color):
        if isinstance(color, (tuple, list)) and len(color) == 3:
            return tuple(map(int, color))
        if isinstance(color, str):
            c = color.strip().lower()
            if c in self.COLOR_MAP:
                return self.COLOR_MAP[c]
        raise ValueError(f"Unknown color: {color}")

    def led(self, index, color, brightness=int(255*0.6)):
        """High-level simple LED control."""
        if not self.ser:
            print("[ERROR] Board not initialized")
            return

        try:
            r, g, b = self._normalize_color(color)
            self.LED(index, r, g, b, int(brightness))
        except Exception as e:
            print("[LED ERROR]", e)

    def led_off(self, index):
        """Turn off LED completely."""
        self.LED(index, 0, 0, 0, 0)

    def led_flash_on(self, index):
        """Bright flashlight color."""
        self.LED(index, 20, 255, 222, 230)

    def led_alert(self, index, color='red', brightness=int(255*0.6)):
        """Alert mode (NO blinking)."""
        try:
            r, g, b = self._normalize_color(color)
            self.LED(index, r, g, b, int(brightness))
        except Exception as e:
            print("[ALERT ERROR]", e)

    def set_led_manual(self, index, r, g, b, brightness=int(255*0.6)):
        """Raw manual control."""
        r = max(0, min(255, int(r)))
        g = max(0, min(255, int(g)))
        b = max(0, min(255, int(b)))
        brightness = max(0, min(255, int(brightness)))
        self.LED(index, r, g, b, brightness)

    # ---------------------------------------------------------
    # PRESET SIGNAL FUNCTIONS
    # ---------------------------------------------------------
    def warning(self, index):
        self.led(index, 'signal_yellow')

    def danger(self, index):
        self.led(index, 'signal_red')
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

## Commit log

2026-09-24 Initial commit: Team 27 Inter IIT warehouse rover submission
    [BOM.csv, arena2.sdf, arena_test.sdf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]
2026-09-24 Rename submission folders to code, hardware, vision, and docs
    [BOM.csv, arena2.sdf, arena_test.sdf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]
2026-09-24 Polish GitHub landing page with photos, CAD drawings, and architecture
